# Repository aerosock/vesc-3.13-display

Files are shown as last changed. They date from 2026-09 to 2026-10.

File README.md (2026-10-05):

>[!WARNING]  
>for the dear anti-ai purists, this project was in part made with its help.

# UART display for VESC-based controllers on Waveshare ESP32-S3-LCD-3.16 module
<p align="center">
        
        
      </p>

My spin on the VESC display. 

Simple 3D printed case, uses two MX style keyboard switches for navigation. Communicates with the VESC through UART, which does alright even on my 1m+ long wire harness. 

Based on this [module](https://www.waveshare.com/product/esp32-related/boards-kits/esp32-s3/esp32-s3-lcd-3.16.htm).
820×320(20,5:8 ratio) ST7701 RGB display, ESP32-S3 microcontroller

Tested on Flipsky 75100 V1(the cheapest crap ever) with firmware version 7. Might misbehave with other controllers because cuh.

Shows live stats(speed, wattage, amperage, voltage, battery info), features long term statistics, capable of changing most basic VESC settings on the go, supports USB to UART bridge for programming through desktop VESC Tool as well as TCP WIFI connection for the mobile app.

---

## Wiring
schematic

I made this beautiful illustration because im too lazy to open easyeda. basically really simple. 

the screen sips like 300-500mA tops so you can feed it from the on board 5v from the vesc from my experience

the 3v3 on the uart connector is a power output not input so you dont want to connect it anywhere

the only 5v input is unfortunately on the usb plug and it means you have to do solderslop if you dont have the correct size plug for it(waveshare only bundles 2 plugs, for uart and i2c)

sda and scl pins on i2c port can be used as regular digital gpio ports as well, that how the buttons are implemented without an i2c splitter thingy

---

## Screens & Features

There are 2 dashboard styles. 

one more practical with the duty cycle bar on the top 

05_horizontal_field_weakening

and another one with an analog style tachometer-duty cycle scale. it also does cool needle swipe on start up like motorcycles and cars!!!!

03_analog_field_weakening

statistics screens and whatnot are pretty self explanatory so im not going to say anything about them

settings are a pretty basic menu that can be opened by holding down BTN1 and scrolled up and down with BTN1/BTN2. press BTN1+BTN2 to choose/save. hold BTN2 to go back in menu and on dashboard to reset trip.

## ai slop excerpt regarding other features

### 5. Transparent VESC USB Bridge (`SCREEN_VESC_BRIDGE`)
* Plugs into your PC with a USB-C cable while connected to the bike.
* Acts as a transparent serial forwarding bridge between PC VESC Tool and the Flipsky controller.
* Configured with 4KB FreeRTOS queues on USB CDC and hardware UART so that large packets (like `COMM_SET_MCCONF`, ~650 bytes) write without packet drops or timeouts.

### 6. Wireless Wi-Fi TCP Bridge (`SCREEN_WIFI_BRIDGE`)
* Launches an on-demand 2.4 GHz SoftAP on the ESP32-S3:
  * **SSID:** `VESC-DASH-AP` (Open, no password)
  * **IP:** `192.168.4.1`
  * **Port:** `6510` (VESC standard TCP port)
* Connect your phone to the Wi-Fi network and open the mobile VESC Tool app → Connection → TCP → `192.168.4.1:6510`.
* Radio completely powers down when exiting bridge mode to eliminate idle power draw.

---

## Physical case



pretty simple design. 7mm inner standoffs holding up the board to leave space for wiring. M2x10 screws get there... almost perfectly)

has mounting points for handlebar mounts, basically 2 small pegs and a long m3 screw going through the mount and screwing on with a nut on the inside. it hold fine. the mounts i have for regular 31.8mm handlebars. the gap i left in them is pretty small but when printing from petg they slide onto the handlebars even at the thickest point alright. secured with a pair M3 screw+nut.

buttons are massacred mx style switches. i used outemu blues because i have a lot of them and they have large windows for rgb diodes which can be cut off to make the casing footprint only 10.5x14 as opposed to default 14x14 which uhhh saves some space. you can just modify the casing and the top plate a bit to fit them fully or redesign for some better buttons. keycaps on mine i also modeled, nothing much to say about them except for the fact that i printed them with a circular pattern because the stem was getting messed up with other infill patterns. the switches are then glued into the casing really at any depth you like, just make sure that there's enough space for keycaps.

everything uses M3 hardware except for the pcb standoffs. i dont know lengths but if you dont already have a big box of different M3 bolts you should definitely get one.

### Important thing to note is that im a dumbass and most of the holes are a bit too small. i just drilled them out to proper diameters with a drill.

also im not sure about the exact waterproofness of the case. i put silicone rubber around all of the holes and gaps but i have yet to test how they hold up. maybe you could just make some gasket from like tpu and that would be better. 

as already said i printed with petg, i think 0.20mm layer height, 100% infill ofc. had a hard time getting the top frame to stick to the PEI plate so i had to print it with a skirt.

i provided the models for the top frame, bottom casing and the mounting brackets in STL and STEP. also here's the [onshape link](https://cad.onshape.com/documents/30012e10ce4cb7aa290a9fdc/w/881d1dbb9680ce4c04a9ae5d/e/2c86da4f851fc89c557b4d4e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) for easier further modification

### how it looks on the bike assembled



---

## Building and Flashing(had ai generate this one and the next section. it's either self explanatory basics and you dont need to read it or you will ask ai how to do it anyway)

### Requirements
* [PlatformIO CLI](https://platformio.org/) (`pio`) or VS Code with the PlatformIO extension.
* Quality USB-C cable (ensure it carries data lines, not charge-only).

### Compile and Flash via USB
```bash
# Clone the repository
git clone https://github.com/aerosock/vesc-3.13-display.git
cd vesc-3.13-display

# Build and upload to connected ESP32-S3
pio run -t upload

# Open serial console (115200 baud)
pio run -t monitor
```

### Linux Permissions (udev)
If upload fails with permission errors on `/dev/ttyACM0`:
```bash
# Add yourself to dialout group
sudo usermod -aG dialout $USER

# Or run the included setup script (Fedora/Ubuntu):
chmod +x scripts/setup_fedora.sh
./scripts/setup_fedora.sh
```

---

## Hardware Quirks & Troubleshooting

* **Green On-Board LED stays lit:**  
  The small green LED on the Waveshare board is directly wired to the 3.3V power rail after the LDO. It is a hardware power indicator, not connected to a GPIO pin. It cannot be disabled in software. If you don't want it visible in an enclosure, cover it with black electrical tape or desolder its current-limiting resistor.

* **ESP32-S3 doesn't enter bootloader automatically:**  
  Hold down the **BOOT** button (GPIO 0), press and release the **RESET** button, then release **BOOT**. This forces the chip into ROM download mode. Run `pio run -t upload` again.

* **Writing motor settings in VESC Tool fails over USB:**  
  VESC Tool configuration writes send a single 500–650+ byte burst. In standard Arduino ESP32 cores, USB CDC buffers default to 256 bytes, truncating the write packet. This firmware configures 4096-byte queues before `Serial.begin()`. If you modify `main.cpp`, do not reduce buffer sizes.

* **Testing on a desk without a bike (Simulation Mode):**  
  In `include/board_config.h`, set:
  ```cpp
  #define SIMULATION_MODE 1
  ```
  This runs an automated 45-second simulated ride cycle with acceleration, steady cruise, and field weakening without requiring a VESC connection. Set back to `0` for real UART operation.

* **Native Linux Headless Simulator:**  
  You can build and test all 13 screens on a Linux desktop without any ESP32 hardware:
  ```bash
  chmod +x tools/simulator/build_and_run.sh
  ./tools/simulator/build_and_run.sh
  ```
  Screenshots of every screen state are rendered to `tools/simulator/screenshots/`.

# the end

  that's about it. shout out to mr antigravity for coding and mr ENGINEER jooj from discord for moral and technical support.

  if you have any improvements/bugs - issues and bugs on github are very welcome. i daily drive this thing myself and will try to continuously improve on it. 

  in general im pretty happy with how it turned out considering how little engineering experience i possess. i was very worried about the brightness of the display being lackluster but it proved to be enough even on sunny days. the esp is also surprisingly good at driving that display - the framerate and responsiveness are great! 

  total costs for this project should be only a few dozen euro - the display module can be had for 20eur shipped from aliexpress, and the rest are just basic DIY materials.

  ## known issues/TODO list: 
  - add ON/OFF functionality of some sorts?
  - fix 3d models to be less shit
  - work on the UI since element spacing and whatnot kinda suck
  - test WIFI and USB bridges further. had some issues with them that were allegedly fixed but not 100%
  - make some better pictures lmao with a clean camera lens 
  - add support for displaying regen braking(my bike isnt DD)
  - automatically adjusting the duty cycle display depending on whether field weakening is on or off
  - battery percentage and wh numbers seem to be at the very least extremely innaccurate

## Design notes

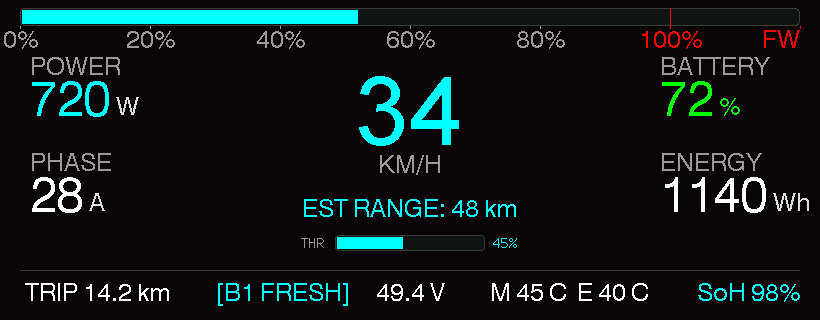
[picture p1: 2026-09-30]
tools/simulator/screenshots/04_horizontal_cruising.png

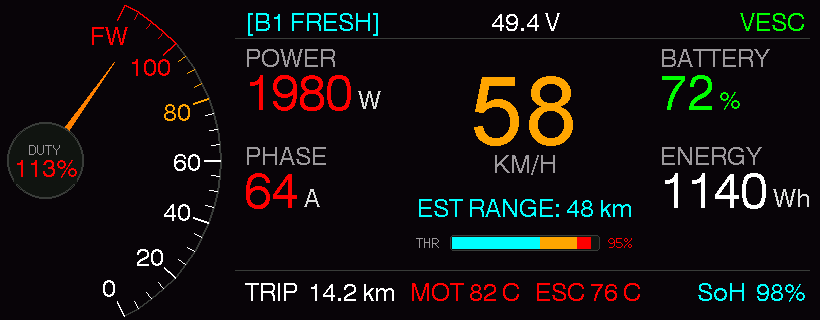
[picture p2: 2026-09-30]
tools/simulator/screenshots/03_analog_field_weakening.png

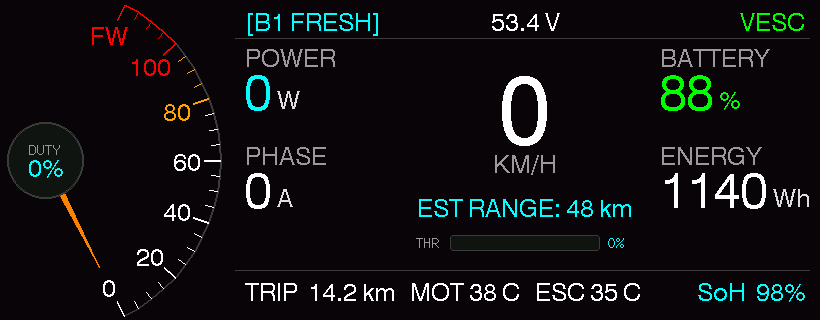
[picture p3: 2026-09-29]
tools/simulator/screenshots/01_analog_idle.png

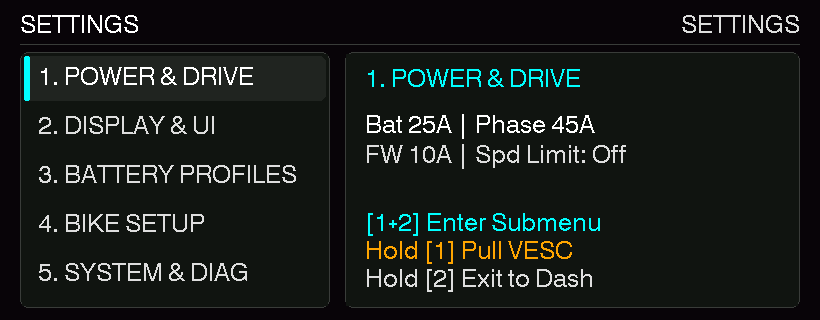
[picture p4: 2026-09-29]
tools/simulator/screenshots/08_settings_root.png

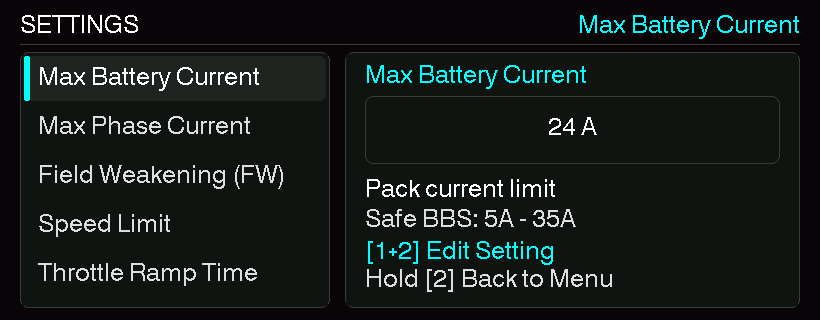
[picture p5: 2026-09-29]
tools/simulator/screenshots/11_settings_display_style.png

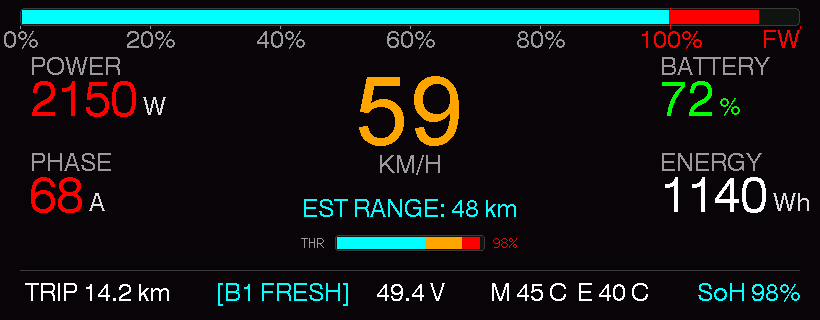
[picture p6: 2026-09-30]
tools/simulator/screenshots/05_horizontal_field_weakening.png

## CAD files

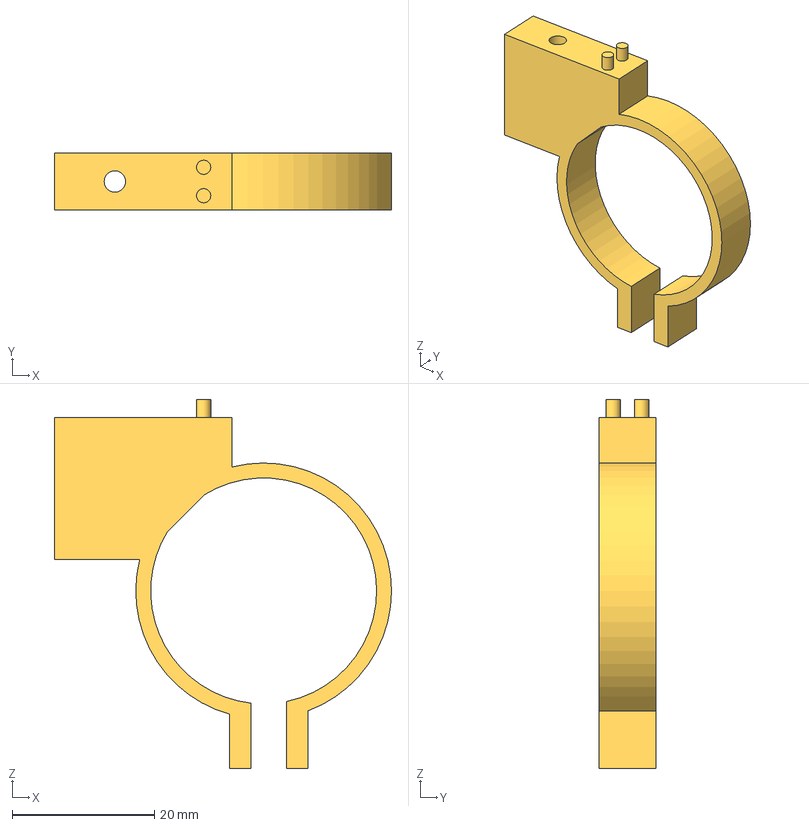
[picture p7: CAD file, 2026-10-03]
3dmodels/step/display handlebar holder.step
47.4 x 8.00 x 51.9 mm

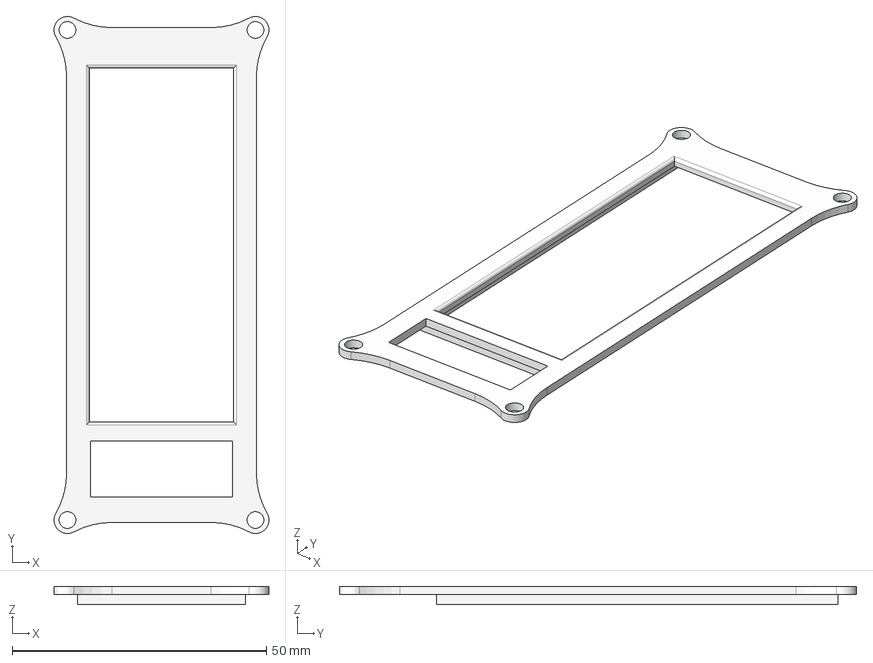
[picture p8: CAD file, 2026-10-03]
3dmodels/step/display top frame.step
42.3 x 101.7 x 3.60 mm

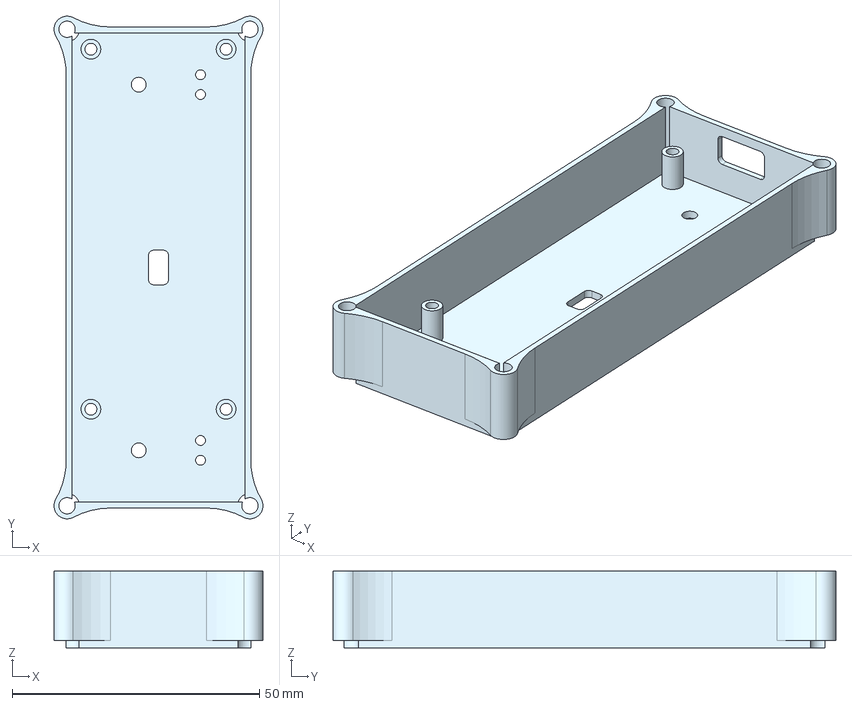
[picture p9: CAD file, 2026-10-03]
3dmodels/step/display bottom case.step
42.3 x 101.7 x 15.5 mm

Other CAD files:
3dmodels/stl/display bottom case.stl
3dmodels/stl/display handlebar holder.stl
3dmodels/stl/display top frame.stl

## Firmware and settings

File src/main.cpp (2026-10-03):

#include <Arduino.h>
#include "board_config.h"
#include "dash_types.h"
#include "display_driver.h"
#include "dash_renderer.h"
#include "settings_manager.h"
#include "battery_manager.h"
#include "buttons.h"
#include "vesc_uart.h"

// Active Telemetry State
static DashTelemetry telemetry;

void setup() {
    // 1. Initialize USB CDC Serial Monitor with 4KB buffers for VESC configuration packets
    Serial.setRxBufferSize(4096);
    Serial.setTxBufferSize(4096);
    Serial.begin(115200);
    delay(500);
    Serial.println("\n=============================================");
    Serial.println(" Waveshare ESP32-S3-LCD-3.16 eBike Dashboard ");
    Serial.println(" Clean OEM Instrument Cluster UI (820x320)");
    Serial.println(" Target: Flipsky 75100 V1 (VESC UART)");
    Serial.println(" Motor: Bafang BBS Mid-Drive (No Regen)");
    Serial.println("=============================================");

    // 2. Initialize Persistent Settings
    Settings.begin();
    Serial.printf("[OK] Settings loaded: MaxBat=%dA, MaxPhase=%dA, FW=%dA, Style=%d\n",
                  Settings.get().max_battery_amps,
                  Settings.get().max_phase_amps,
                  Settings.get().field_weak_amps,
                  Settings.get().dash_style);

    // 3. Initialize Battery Profile & Health Learning System
    Battery.begin();
    Serial.printf("[OK] Battery Manager initialized: Active Profile %d (%s)\n",
                  Battery.getActiveProfileIndex(),
                  Battery.getProfile(Battery.getActiveProfileIndex()).name);

    // 4. Initialize Telemetry State
    telemetry.speed_kmh           = 0.0f;
    telemetry.duty_cycle_pct      = 0.0f;
    telemetry.rpm                 = 0.0f;
    telemetry.throttle_pct        = 0.0f;
    telemetry.voltage             = 0.0f;
    telemetry.current_amps        = 0.0f;
    telemetry.phase_amps          = 0.0f;
    telemetry.power_watts         = 0.0f;
    telemetry.amphours_used       = 0.0f;
    telemetry.battery_profile_id  = Battery.getActiveProfileIndex();
    telemetry.battery_pct         = Battery.getFusedSocPct();
    telemetry.remaining_wh        = Battery.getRemainingWh();
    telemetry.battery_health_soh  = Battery.getProfile(Battery.getActiveProfileIndex()).health_soh_pct;
    telemetry.est_range_km        = Battery.getEstRangeKm();
    telemetry.temp_motor          = 36.0f;
    telemetry.temp_esc            = 31.0f;
    telemetry.trip_km             = 0.0f;
    telemetry.odo_km              = 142.0f;
    telemetry.stats.reset();
    telemetry.screen              = SCREEN_RIDE_DASH;
    telemetry.vesc_connected      = false;
    telemetry.uptime_sec          = 0;

    // 5. Initialize Physical Navigation Buttons (SCL=GPIO 7, SDA=GPIO 15)
    Buttons.begin();
    Serial.println("[OK] Navigation Buttons initialized on SCL (GPIO 7) and SDA (GPIO 15)");

    // 6. Initialize ST7701 Display and Backlight
    Serial.println("[INFO] Initializing ST7701 Display Driver...");
    if (!Display.init()) {
        Serial.println("[ERROR] Display initialization failed!");
    } else {
        Serial.println("[OK] Display initialized with Octal PSRAM frame buffer (820x320 landscape).");
    }
    uint8_t br = (uint8_t)map(Settings.get().brightness_pct, 0, 100, 0, 255);
    Display.setBrightness(br);

    // 7. Initialize Renderer
    Renderer.begin(&Display);
    if (Settings.get().dash_style == STYLE_ANALOG_DIAL) {
        Renderer.triggerNeedleSweep();
    }

    // 8. Initialize VESC UART or Simulation Engine
    Vesc.begin();
#if SIMULATION_MODE
    Serial.println("[MODE] Self-Test Simulation Mode Active.");
    Serial.println("       Set SIMULATION_MODE in include/board_config.h to 0 for live Flipsky 75100 UART.");
#else
    Serial.println("[MODE] Live Flipsky 75100 VESC UART Mode Active (TX: GPIO 43, RX: GPIO 44).");
#endif

    Serial.println("[OK] Setup complete. Entering main render loop.");
}

void loop() {
    static uint32_t last_render_ms = 0;
    static uint32_t last_log_ms = 0;
    static uint32_t boot_ms = millis();
    uint32_t now = millis();

    // 1. Process Physical Button Inputs
    Buttons.update();
    NavAction nav = Buttons.getNavAction();

    if (nav != NAV_NONE) {
        if (Vesc.isBridgeActive()) {
            if (nav == NAV_BTN2_LONG || nav == NAV_BOTH_PRESSED || nav == NAV_BTN1_LONG) {
                if (Vesc.isUsbBridgeActive()) Vesc.exitBridgeMode();
                if (Vesc.isWifiBridgeActive()) Vesc.exitWifiBridgeMode();
                telemetry.screen = SCREEN_RIDE_DASH;
                Renderer.markScreenDirty();
                Renderer.invalidateCache();
            }
        } else if (telemetry.screen == SCREEN_SETTINGS_MENU) {
            Renderer.handleMenuNav(nav, telemetry);
        } else {
            switch (nav) {
                case NAV_BTN1_SHORT: // Previous Screen (Up): Ride Dash <-> Perf Stats <-> Energy Stats
                    {
                        int cur = (int)telemetry.screen;
                        telemetry.screen = (DashboardScreen)((cur - 1 + 3) % 3);
                        if (telemetry.screen == SCREEN_RIDE_DASH && Settings.get().dash_style == STYLE_ANALOG_DIAL) {
                            Renderer.triggerNeedleSweep();
                        }
                        Serial.printf("[NAV] BTN1 Short: Switched to Screen ID %d\n", (int)telemetry.screen);
                    }
                    break;

                case NAV_BTN2_SHORT: // Next Screen (Down): Ride Dash -> Energy Stats -> Perf Stats -> Ride Dash
                    {
                        int cur = (int)telemetry.screen;
                        telemetry.screen = (DashboardScreen)((cur + 1) % 3);
                        if (telemetry.screen == SCREEN_RIDE_DASH && Settings.get().dash_style == STYLE_ANALOG_DIAL) {
                            Renderer.triggerNeedleSweep();
                        }
                        Serial.printf("[NAV] BTN2 Short: Switched to Screen ID %d\n", (int)telemetry.screen);
                    }
                    break;

                case NAV_BTN1_LONG: // Button 1 Long Press: Open Settings Menu directly
                    telemetry.screen = SCREEN_SETTINGS_MENU;
                    Serial.println("[NAV] BTN1 Long: Opened Settings Menu");
                    break;

                case NAV_BTN2_LONG: // Button 2 Long Press: Reset Trip Odometer & Statistics
                    telemetry.trip_km = 0.0f;
                    telemetry.stats.reset();
                    Serial.println("[NAV] BTN2 Long: Reset Trip Odometer and Statistics to 0.0");
                    break;

                case NAV_BOTH_PRESSED: // BTN1 + BTN2: Fast Toggle Active Battery Profile
                    {
                        uint8_t next_p = (Settings.get().active_battery_profile == 0) ? 1 : 0;
                        Settings.get().active_battery_profile = next_p;
                        Battery.setActiveProfile(next_p);
                        Settings.save();
                        Serial.printf("[NAV] BTN1+BTN2 Short: Fast Toggled Battery Profile: %d (%s)\n",
                                      next_p, Battery.getProfile(next_p).name);
                    }
                    break;

                default:
                    break;
            }
        }
    }

    // 2. Update Telemetry or Forward Bridge Traffic
    if (Vesc.isBridgeActive()) {
        Vesc.updateBridge();
    } else {
        Vesc.update(telemetry);
    }
    telemetry.uptime_sec = (now - boot_ms) / 1000;

    // 3. Render at smooth ~30 FPS rate (throttled to 5 FPS in bridge mode to maximize USB/UART throughput)
    uint32_t render_interval = Vesc.isBridgeActive() ? 200 : 33;
    if (now - last_render_ms >= render_interval) {
        last_render_ms = now;
        Renderer.render(telemetry);
        if (Vesc.isBridgeActive()) {
            Vesc.updateBridge();
        }
    }

    // 4. Debug print over USB Serial every 2 seconds (only when bridge is inactive)
    if (!Vesc.isBridgeActive() && (now - last_log_ms >= 2000)) {
        last_log_ms = now;
        Serial.printf("[DASH] Screen: %d | Spd: %.1f km/h | Duty: %.1f%% | Bat: %.1fV (%.0f%%) | Cur: %.1fA | Pha: %.1fA | Est: %.1fkm\n",
                      (int)telemetry.screen, telemetry.speed_kmh, telemetry.duty_cycle_pct, telemetry.voltage,
                      telemetry.battery_pct, telemetry.current_amps, telemetry.phase_amps, telemetry.est_range_km);
    }
}

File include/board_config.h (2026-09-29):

#pragma once

#include <Arduino.h>

// ==============================================================================
// Waveshare ESP32-S3-LCD-3.16 Board Configuration & Pin Mapping
// ==============================================================================

// Display Dimensions (Physical panel: 320x820, rendered in landscape: 820x320)
#define LCD_WIDTH   820
#define LCD_HEIGHT  320

// ST7701 Sideband SPI Command Interface
#define LCD_PIN_CS      0   // Shared with BOOT button (used only after init)
#define LCD_PIN_MOSI    1
#define LCD_PIN_SCK     2
#define LCD_PIN_RST     16

// ST7701 RGB Parallel Timing & Clock
#define LCD_PIN_HSYNC   38
#define LCD_PIN_VSYNC   39
#define LCD_PIN_DE      40
#define LCD_PIN_PCLK    41
#define LCD_FREQ_HZ     14000000 // 14 MHz RGB clock (eliminates PSRAM DMA FIFO underrun ripples while maintaining 40Hz refresh)

// ST7701 RGB Bus Data Pins
// Red (5-bit: R0 - R4)
#define LCD_PIN_R0      17
#define LCD_PIN_R1      46
#define LCD_PIN_R2      3
#define LCD_PIN_R3      8
#define LCD_PIN_R4      18

// Green (6-bit: G0 - G5)
#define LCD_PIN_G0      14
#define LCD_PIN_G1      13
#define LCD_PIN_G2      12
#define LCD_PIN_G3      11
#define LCD_PIN_G4      10
#define LCD_PIN_G5      9

// Blue (5-bit: B0 - B4)
#define LCD_PIN_B0      21
#define LCD_PIN_B1      5
#define LCD_PIN_B2      45
#define LCD_PIN_B3      48
#define LCD_PIN_B4      47

// Backlight (Inverted PWM on GPIO 6)
#define LCD_PIN_BL      6
#define BL_PWM_CHANNEL  1
#define BL_PWM_FREQ     50000
#define BL_PWM_RES      8

// ==============================================================================
// Buttons Connected to I2C Port
// ==============================================================================
// On Waveshare ESP32-S3-LCD-3.16, the SH1.0 4-PIN I2C connector provides:
// Pin 1: 3V3
// Pin 2: GND
// Pin 3: SDA -> GPIO 15
// Pin 4: SCL -> GPIO 7
//
// When 2 buttons are connected between SCL -> GND and SDA -> GND:
#define PIN_BTN_1       7    // Button 1 (SCL pin): Toggle Style / Re-trigger R1 Sweep
#define PIN_BTN_2       15   // Button 2 (SDA pin): Cycle Ride Mode / Reset Trip

// Optional Onboard BOOT button
#define PIN_BTN_BOOT    0

// ==============================================================================
// VESC UART Interface (Flipsky 75100 V1 Basic)
// ==============================================================================
// Onboard PH1.0 4-PIN UART Header:
// TX (ESP32-S3 TXD) -> GPIO 43  ==> Connects to Flipsky RX
// RX (ESP32-S3 RXD) -> GPIO 44  ==> Connects to Flipsky TX
#define VESC_UART_PORT      Serial0
#define VESC_UART_TX_PIN    44
#define VESC_UART_RX_PIN    43
#define VESC_UART_BAUDRATE  115200

// Battery Analog Sensing (onboard divider if used)
#define PIN_BATTERY_ADC     4

// ==============================================================================
// Feature Flags
// ==============================================================================
// 1 = Self-running simulation mode (test without VESC connected)
// 0 = Live VESC UART communication with Flipsky 75100
#define SIMULATION_MODE     0

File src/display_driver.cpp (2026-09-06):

#include "display_driver.h"
#include <driver/ledc.h>

DisplayDriver Display;

// ST7701 initialization command list for Waveshare 3.16" 320x820 panel
const uint8_t *WaveshareST7701Panel::getInitCommands(uint8_t listno) const {
    static constexpr const uint8_t list0[] = {
        0xFF, 5, 0x77, 0x01, 0x00, 0x00, 0x13,
        0xEF, 1, 0x08,
        0xFF, 5, 0x77, 0x01, 0x00, 0x00, 0x10,
        0xC0, 2, 0xE5, 0x02,
        0xC1, 2, 0x15, 0x0A,
        0xC2, 2, 0x07, 0x02,
        0xCC, 1, 0x10,
        0xB0, 16, 0x00, 0x08, 0x51, 0x0D, 0xCE, 0x06, 0x00, 0x08,
                  0x08, 0x24, 0x05, 0xD0, 0x0F, 0x6F, 0x36, 0x1F,
        0xB1, 16, 0x00, 0x10, 0x4F, 0x0C, 0x11, 0x05, 0x00, 0x07,
                  0x07, 0x18, 0x02, 0xD3, 0x11, 0x6E, 0x34, 0x1F,
        0xFF, 5, 0x77, 0x01, 0x00, 0x00, 0x11,
        0xB0, 1, 0x4D,
        0xB1, 1, 0x37,
        0xB2, 1, 0x87,
        0xB3, 1, 0x80,
        0xB5, 1, 0x4A,
        0xB7, 1, 0x85,
        0xB8, 1, 0x21,
        0xB9, 2, 0x00, 0x13,
        0xC0, 1, 0x09,
        0xC1, 1, 0x78,
        0xC2, 1, 0x78,
        0xD0, 1, 0x88,
        0xE0, 3 + CMD_INIT_DELAY, 0x80, 0x00, 0x02, 100,
        0xE1, 11, 0x0F, 0xA0, 0x00, 0x00, 0x10, 0xA0, 0x00, 0x00, 0x00, 0x60, 0x60,
        0xE2, 13, 0x30, 0x30, 0x60, 0x60, 0x45, 0xA0, 0x00, 0x00, 0x46, 0xA0, 0x00, 0x00, 0x00,
        0xE3, 4, 0x00, 0x00, 0x33, 0x33,
        0xE4, 2, 0x44, 0x44,
        0xE5, 16, 0x0F, 0x4A, 0xA0, 0xA0, 0x11, 0x4A, 0xA0, 0xA0,
                  0x13, 0x4A, 0xA0, 0xA0, 0x15, 0x4A, 0xA0, 0xA0,
        0xE6, 4, 0x00, 0x00, 0x33, 0x33,
        0xE7, 2, 0x44, 0x44,
        0xE8, 16, 0x10, 0x4A, 0xA0, 0xA0, 0x12, 0x4A, 0xA0, 0xA0,
                  0x14, 0x4A, 0xA0, 0xA0, 0x16, 0x4A, 0xA0, 0xA0,
        0xEB, 7, 0x02, 0x00, 0x4E, 0x4E, 0xEE, 0x44, 0x00,
        0xED, 16, 0xFF, 0xFF, 0x04, 0x56, 0x72, 0xFF, 0xFF, 0xFF,
                  0xFF, 0xFF, 0xFF, 0x27, 0x65, 0x40, 0xFF, 0xFF,
        0xEF, 6, 0x08, 0x08, 0x08, 0x40, 0x3F, 0x64,
        0xFF, 5, 0x77, 0x01, 0x00, 0x00, 0x13,
        0xE8, 2, 0x00, 0x0E,
        0xFF, 5, 0x77, 0x01, 0x00, 0x00, 0x00,
        0x11, 0 + CMD_INIT_DELAY, 120,
        0xFF, 5, 0x77, 0x01, 0x00, 0x00, 0x13,
        0xE8, 2 + CMD_INIT_DELAY, 0x00, 0x0C, 10,
        0xE8, 2, 0x00, 0x00,
        0xFF, 5, 0x77, 0x01, 0x00, 0x00, 0x00,
        0x3A, 1, 0x55,
        0x36, 1, 0x00,
        0x35, 1, 0x00,
        0x29, 0 + CMD_INIT_DELAY, 20,
        0xFF, 0xFF
    };
    switch (listno) {
        case 0: return list0;
        default: return nullptr;
    }
}

WaveshareLGFX::WaveshareLGFX() {
    {
        auto cfg = _panel_instance.config();
        cfg.pin_cs        = LCD_PIN_CS;
        cfg.pin_rst       = LCD_PIN_RST;
        cfg.memory_width  = 320;
        cfg.memory_height = 820;
        cfg.panel_width   = 320;
        cfg.panel_height  = 820;
        cfg.offset_x      = 0;
        cfg.offset_y      = 0;
        cfg.rgb_order     = true;
        cfg.invert        = false;

        _panel_instance.config(cfg);
    }

    {
        auto cfg = _panel_instance.config_detail();
        cfg.pin_cs    = LCD_PIN_CS;
        cfg.pin_sclk  = LCD_PIN_SCK;
        cfg.pin_mosi  = LCD_PIN_MOSI;
        cfg.use_psram = 1; // 524KB frame buffer allocated in Octal PSRAM
        _panel_instance.config_detail(cfg);
    }

    {
        auto cfg = _bus_instance.config();
        cfg.panel = &_panel_instance;

        // RGB Bus Pins (16-bit 565)
        cfg.pin_d0  = LCD_PIN_B0;
        cfg.pin_d1  = LCD_PIN_B1;
        cfg.pin_d2  = LCD_PIN_B2;
        cfg.pin_d3  = LCD_PIN_B3;
        cfg.pin_d4  = LCD_PIN_B4;
        cfg.pin_d5  = LCD_PIN_G0;
        cfg.pin_d6  = LCD_PIN_G1;
        cfg.pin_d7  = LCD_PIN_G2;
        cfg.pin_d8  = LCD_PIN_G3;
        cfg.pin_d9  = LCD_PIN_G4;
        cfg.pin_d10 = LCD_PIN_G5;
        cfg.pin_d11 = LCD_PIN_R0;
        cfg.pin_d12 = LCD_PIN_R1;
        cfg.pin_d13 = LCD_PIN_R2;
        cfg.pin_d14 = LCD_PIN_R3;
        cfg.pin_d15 = LCD_PIN_R4;

        // Timing & Sync Pins
        cfg.pin_henable = LCD_PIN_DE;
        cfg.pin_vsync   = LCD_PIN_VSYNC;
        cfg.pin_hsync   = LCD_PIN_HSYNC;
        cfg.pin_pclk    = LCD_PIN_PCLK;
        cfg.freq_write  = LCD_FREQ_HZ;

        cfg.hsync_polarity    = 0;
        cfg.hsync_front_porch = 30;
        cfg.hsync_pulse_width = 6;
        cfg.hsync_back_porch  = 30;

        cfg.vsync_polarity    = 0;
        cfg.vsync_front_porch = 20;
        cfg.vsync_pulse_width = 40;
        cfg.vsync_back_porch  = 20;

        cfg.pclk_idle_high    = 1;

        _bus_instance.config(cfg);
        _panel_instance.setBus(&_bus_instance);
    }

    setPanel(&_panel_instance);
}

DisplayDriver::DisplayDriver() : _brightness(255) {}

bool DisplayDriver::init() {
    // 1. Initialize Inverted Backlight PWM first (GPIO 6, 50kHz, Channel 1)
    ledc_timer_config_t timer_conf = {
        .speed_mode = LEDC_LOW_SPEED_MODE,
        .duty_resolution = (ledc_timer_bit_t)BL_PWM_RES,
        .timer_num = LEDC_TIMER_3,
        .freq_hz = BL_PWM_FREQ,
        .clk_cfg = LEDC_AUTO_CLK,
    };
    ledc_timer_config(&timer_conf);

    ledc_channel_config_t channel_conf = {
        .gpio_num = LCD_PIN_BL,
        .speed_mode = LEDC_LOW_SPEED_MODE,
        .channel = (ledc_channel_t)BL_PWM_CHANNEL,
        .intr_type = LEDC_INTR_DISABLE,
        .timer_sel = LEDC_TIMER_3,
        // Inverted: 255 brightness is 0 duty (active-low pulls to GND)
        .duty = (uint32_t)(255 - _brightness),
        .hpoint = 0,
    };
    ledc_channel_config(&channel_conf);
    setBrightness(_brightness);
    delay(20);

    // 2. Initialize ST7701 panel & RGB bus via LovyanGFX
    if (!_lcd.init()) {
        Serial.println("[DISPLAY ERROR] _lcd.init() returned false!");
        return false;
    }

    _lcd.setColorDepth(16);
    _lcd.setRotation(1); // Landscape mode: 820 x 320
    _lcd.fillScreen(0x0000);

    Serial.printf("[DISPLAY OK] Resolution: %d x %d, Rotation: %d\n", _lcd.width(), _lcd.height(), _lcd.getRotation());
    Serial.printf("[DISPLAY OK] Free Heap: %u bytes, Free PSRAM: %u bytes\n", ESP.getFreeHeap(), ESP.getFreePsram());
    return true;
}

void DisplayDriver::setBrightness(uint8_t brightness) {
    _brightness = brightness;
    uint32_t duty = (uint32_t)(255 - brightness);
    ledc_set_duty(LEDC_LOW_SPEED_MODE, (ledc_channel_t)BL_PWM_CHANNEL, duty);
    ledc_update_duty(LEDC_LOW_SPEED_MODE, (ledc_channel_t)BL_PWM_CHANNEL);
}

void DisplayDriver::clear(uint16_t color) {
    _lcd.fillScreen(color);
}

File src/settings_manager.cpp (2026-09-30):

#include "settings_manager.h"

SettingsManager Settings;

SettingsManager::SettingsManager() {
    loadDefaults();
}

void SettingsManager::loadDefaults() {
    _settings.dash_style             = STYLE_ANALOG_DIAL;
    _settings.brightness_pct         = 90;
    _settings.max_battery_amps       = 25;
    _settings.max_phase_amps         = 45;
    _settings.field_weak_amps        = 10;
    _settings.max_speed_kmh          = 0; // Unlimited
    _settings.throttle_ramp_sec      = 0.2f;
    _settings.wheel_diameter_in      = 26.0f;
    _settings.motor_pole_pairs       = 15;
    _settings.gear_ratio             = 1.0f;
    _settings.active_battery_profile = 0;
    _settings.voltage_trim_v         = -0.3f;
    _settings.throttle_adc_channel   = 0; // Default to ADC1 (standard VESC throttle)
}

void SettingsManager::begin() {
    _prefs.begin("ebike_cfg", false);

    if (!_prefs.isKey("cfg_init")) {
        // First boot: save initial defaults
        loadDefaults();
        save();
        _prefs.putBool("cfg_init", true);
        _prefs.putBool("adc_v2_fixed", true);
        Serial.println("[SETTINGS] Initialized default NVS configuration.");
    } else {
        _settings.dash_style             = _prefs.getUChar("style", STYLE_ANALOG_DIAL);
        _settings.brightness_pct         = _prefs.getUChar("bright", 90);
        _settings.max_battery_amps       = _prefs.getUChar("bat_a", 28);
        _settings.max_phase_amps         = _prefs.getUChar("pha_a", 55);
        _settings.field_weak_amps        = _prefs.getUChar("fw_a", 10);
        _settings.max_speed_kmh          = _prefs.getUChar("spd_lim", 0);
        _settings.throttle_ramp_sec      = _prefs.getFloat("t_ramp", 0.2f);
        _settings.wheel_diameter_in      = _prefs.getFloat("wheel", 26.0f);
        _settings.motor_pole_pairs       = _prefs.getUChar("poles", 15);
        _settings.gear_ratio             = _prefs.getFloat("gear", 1.0f);
        _settings.active_battery_profile = _prefs.getUChar("bat_prof", 0);
        _settings.voltage_trim_v         = _prefs.getFloat("v_trim", -0.3f);
        _settings.throttle_adc_channel   = _prefs.getUChar("adc_ch", 0);

        // One-time automatic migration: fix boards that had adc_ch set to 1 by previous buggy default
        if (!_prefs.getBool("adc_v2_fixed", false)) {
            _settings.throttle_adc_channel = 0; // Force default to ADC1
            _prefs.putUChar("adc_ch", 0);
            _prefs.putBool("adc_v2_fixed", true);
            Serial.println("[SETTINGS] Migrated throttle ADC channel to ADC1 (standard).");
        }

        Serial.println("[SETTINGS] Loaded configuration from NVS flash.");
    }
}

void SettingsManager::save() {
    _prefs.putUChar("style", _settings.dash_style);
    _prefs.putUChar("bright", _settings.brightness_pct);
    _prefs.putUChar("bat_a", _settings.max_battery_amps);
    _prefs.putUChar("pha_a", _settings.max_phase_amps);
    _prefs.putUChar("fw_a", _settings.field_weak_amps);
    _prefs.putUChar("spd_lim", _settings.max_speed_kmh);
    _prefs.putFloat("t_ramp", _settings.throttle_ramp_sec);
    _prefs.putFloat("wheel", _settings.wheel_diameter_in);
    _prefs.putUChar("poles", _settings.motor_pole_pairs);
    _prefs.putFloat("gear", _settings.gear_ratio);
    _prefs.putUChar("bat_prof", _settings.active_battery_profile);
    _prefs.putFloat("v_trim", _settings.voltage_trim_v);
    _prefs.putUChar("adc_ch", _settings.throttle_adc_channel);
}

void SettingsManager::resetToDefaults() {
    loadDefaults();
    save();
}

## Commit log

2026-09-06 feat: Waveshare ESP32-S3-LCD-3.16 eBike Dashboard for Flipsky 75100 VESC
    [default_16MB.csv]
2026-09-06 fix(renderer): eliminate number blinking with decoupled zero-flicker text padding
    [dash_renderer.cpp]
2026-09-07 fix(renderer): eliminate speed number blinking with zero-flicker text padding
    [dash_renderer.cpp]
2026-09-07 feat: implement left-hug analog gauge, duty cycle, dual battery profiles, trip stats & interactive settings menu
2026-09-07 fix(ui): left-border needle pivot, right-side dial numbers, card-free spacious widescreen layout, settings menu blanking fix, and clean Celsius rendering
    [dash_renderer.cpp]
2026-09-07 feat(ui): split analytics into energy/perf screens, add Font4 units, fix analog needle clipping & red N, fix duty bar layout, and update button controls
    [buttons.cpp, dash_renderer.cpp, dash_renderer.h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]
2026-09-08 fix(ui): mount duty readout inside analog hub, optimize bottom spacing, eliminate all blinking with zero-flicker sprite, add dynamic color coding, and fix button debounce
    [buttons.cpp, dash_renderer.cpp, dash_renderer.h]
2026-09-08 fix: replace unparented sprite with native text padding to prevent LoadProhibited bootloop
    [dash_renderer.cpp, dash_renderer.h]
2026-09-08 feat(simulator): add native LovyanGFX emulator test harness and fix layout clipping issues
    [dash_renderer.cpp, sim_main.cpp]
2026-09-08 fix(buttons): eliminate tactile switch bounce skipping with 35ms stable debouncer and unit tests
    [buttons.cpp, sim_main.cpp]
2026-09-10 fix(buttons): add chord coincidence window and post-chord release cooldown to prevent accidental repeats
    [buttons.cpp, dash_renderer.cpp, sim_main.cpp]
2026-09-26 feat(display): support COMM_GET_VALUES_SETUP for true wheel ground speed and suppress battery stats on bench PSU
2026-09-29 feat(bridge): implement transparent VESC USB-UART bridge, dynamic menu previews, integer watts, and rock-solid button chords
2026-09-29 feat(settings): add on-demand VESC mcconf pull to display with flash persistence
2026-09-29 fix(analog-ui): resolve needle clipping over scale numbers, rim artifacts, and hub border gouges
    [dash_renderer.cpp]
2026-09-29 fix(analog-ui): gate needle and hub rendering to eliminate DMA scanline tearing ripples
    [dash_renderer.cpp]
2026-09-29 fix(analog-ui): tuck needle base under hub cap and restore 5-layer annular rim to eliminate black notches and red artifacts
    [dash_renderer.cpp]
2026-09-29 fix(analog-ui): solid hub cap layering and change-gating to eliminate all rim clipping and ripples
    [dash_renderer.cpp, sim_main.cpp]
2026-09-30 fix(throttle): default throttle ADC channel to ADC1 and add one-time NVS migration
    [settings_manager.cpp, sim_main.cpp, vesc_uart.cpp]
2026-09-30 fix(bridge): expand USB and UART buffers to 4KB and optimize passthrough loop for large mcconf writes
    [main.cpp, vesc_uart.cpp]
2026-10-03 feat: complete wireless Wi-Fi bridge, 4KB serial queues, and clean documentation
2026-10-03 added 3d models and another readme update
    [display bottom case.step, display bottom case.stl, display handlebar holder.step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]
